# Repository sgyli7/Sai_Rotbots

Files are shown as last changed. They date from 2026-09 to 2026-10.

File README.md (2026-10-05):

# Sai_Rotbots

面向真实世界互动与任务的开源机器人工程。保留轮腿机器人 **Sai_Agent_001**、后备箱平整的 **Sai_Agent_002**，并开发 **Goose V0.1** 与大型双足双手机器人 **Gorilla V0.1**。仓库由 `Sai_Agent_001` 直接改名，提交历史和旧版本发布均保留。

| Robot | Cargo bay | Guide |
|---|---|---|
| Sai_Agent_001 | Original powered opposed pads and belt mechanism | [001](robots/Sai_Agent_001/README.md) |
| Sai_Agent_002 | Continuous flat floor, no moving clamp mechanism | [002](robots/Sai_Agent_002/README.md) |
| Goose_V0.1 | Long-neck biped with a gripping beak; initial training checkpoint | [Goose](robots/Goose_V0.1/README.md) |
| gorilla_v0_1 | AA3 appearance; C15 segmented-foot stage, physical gates open | [Gorilla](robots/gorilla_v0_1/README.md) |

## Gorilla V0.1：AA3 外形与复合脚阶段

Gorilla 以用户确认的 AA3 四视图为唯一外观基准，原图比例优先、高度暂取 2.65 m；目标是双足移动、双手操作与自主复杂任务。当前 [C15 阶段基底](robots/gorilla_v0_1/design/appearance_c15_stage.md)保存实际外壳、有限壁厚主框架和分段前掌/足弓/后跟；已提供同源可编辑模型、七机位实渲及有界几何检查。

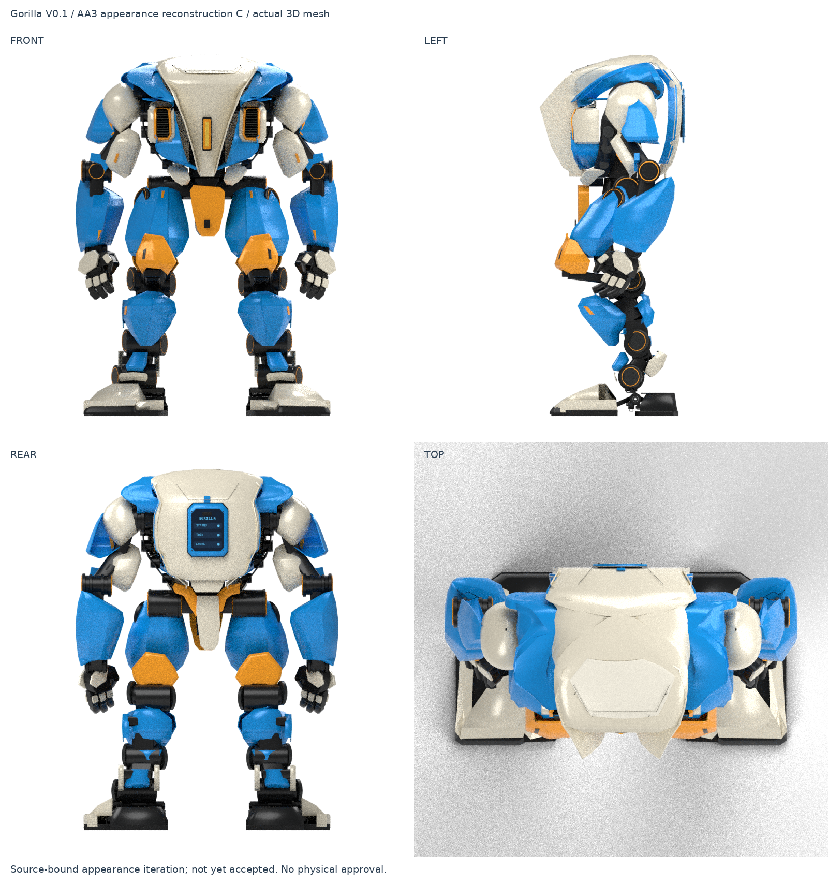
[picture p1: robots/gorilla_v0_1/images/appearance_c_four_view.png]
Gorilla C15 actual source geometry


这是一份可回退的探索候选，外观、完整内部装配、锁止承力和稳定物理合同仍未放行。历史 B 的运行模型与 C15 显示几何分别保留版本；Gorilla 不使用现有轮腿控制器或策略，Bevy 原生物理任务尚待后续验证。下一阶段先闭合真实内部模块的质量、空间、输出、供电与热预算，再细化壳体。

## Goose V0.1：一只幽默又实用的机器人鹅

Goose 的初衷来自 [Untitled Goose Game](https://goose.game/)：把鹅的好奇、探头、歪头、回望、动作停顿和叫声带进真实世界，也让它能帮人做小事。**叼起物品和拖拽物体同等重要**；目标包括指定轻量日用品、布边、空拖鞋、轻篮及小车，支持遥控和“叼过来／拖到指定位置／放下”的指定物自主任务。这些是设计目标，完整任务能力仍待验证。

我们将它视作 [MicroDuck](https://github.com/pollen-robotics/microduck) 的“Max Pro”方向：借鉴双足互动机器人的经验，增加头颈活动范围、真实嘴部夹持和腿脚机动。外观追求简约的鹅感，以可打印曲面、大眼、橙色嘴脚和两侧手动检修门表达角色；检修门不画写实羽毛。最终外观须与实际制造装配一一对应。

### 当前工程装配

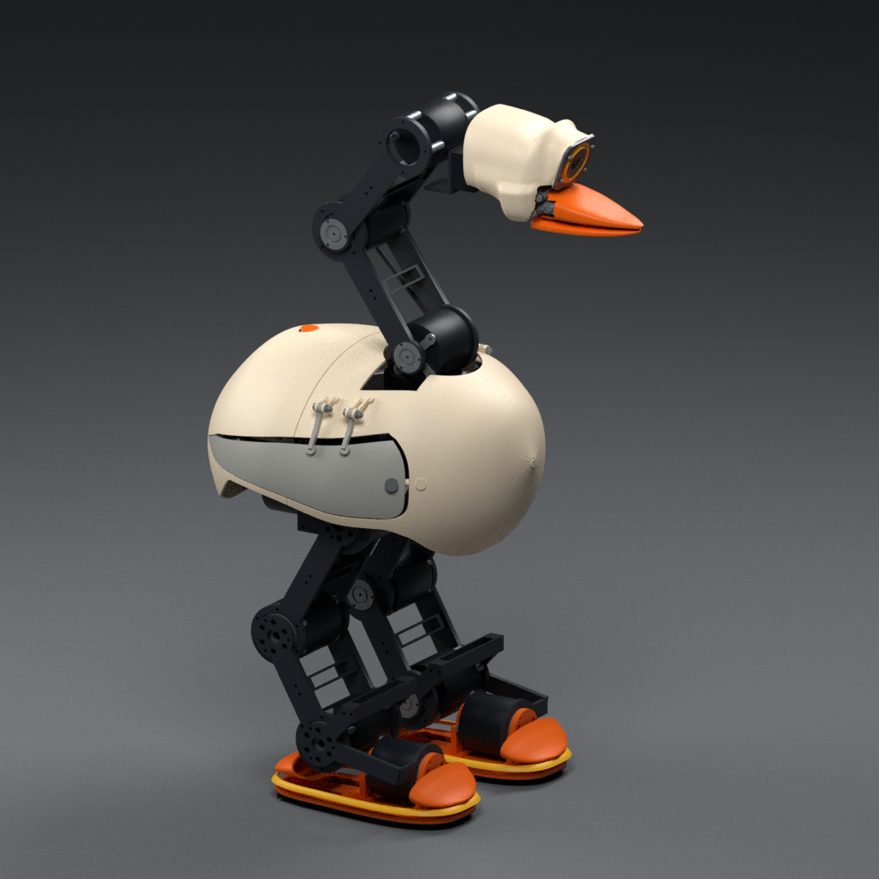
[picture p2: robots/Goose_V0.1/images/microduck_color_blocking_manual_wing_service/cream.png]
Goose V0.1 当前手动翼门候选实际装配渲染


上图直接来自当前 **478 件候选源装配**，不是实物照片或最终制造验收图。单件打印主头壳、相机面板、夹嘴和深色承力结构分别承担实际功能。当前候选有 **18 个主动轴、约 10.40 kg 条件质量**；闭合零位包围尺寸约 **43.4 × 26.7 × 64.2 cm**（长 × 宽 × 高），姿态变化会改变外部包围尺寸。质量含设计预留，尚非实物称重。两侧检修门已加入实际手动铰链和关闭保持；上沿接缝和外露支臂仍待最终审美与制造资格。

| Cream 奶油白 | Graphite 石墨灰 |
|---|---|
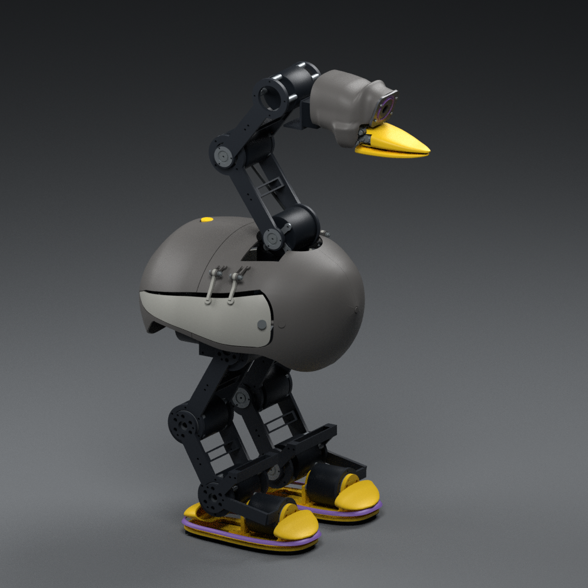
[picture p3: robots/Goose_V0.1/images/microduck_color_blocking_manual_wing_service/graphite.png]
Graphite
| Cream |  |
| Lavender 薰衣草紫 | Sky 天空蓝 |
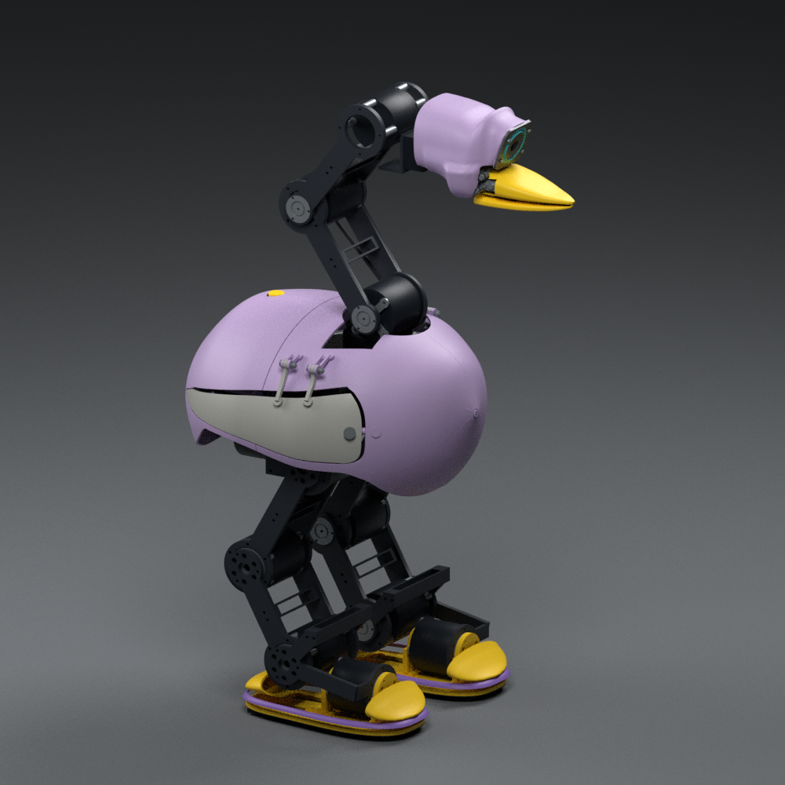
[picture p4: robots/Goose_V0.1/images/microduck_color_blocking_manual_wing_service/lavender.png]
Lavender
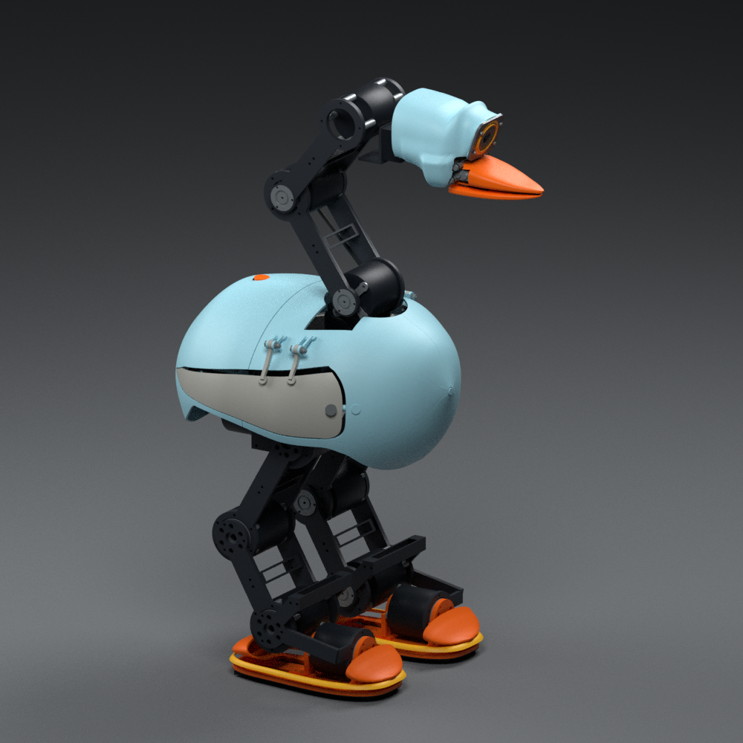
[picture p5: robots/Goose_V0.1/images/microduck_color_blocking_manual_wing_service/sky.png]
Sky
|  |  |

四款使用同版几何、同镜头与灯光，分别配置主壳、中性检修门／脸板、深色骨架、嘴脚及眼圈／鞋边辅色；见[配色与源身份记录](robots/Goose_V0.1/design/manual_wing_service_checkpoint.md)。

### 设计图与外观演进

| 早期 R2 尖嘴概念 | 已确认的阶段性外观基线 |
|---|---|
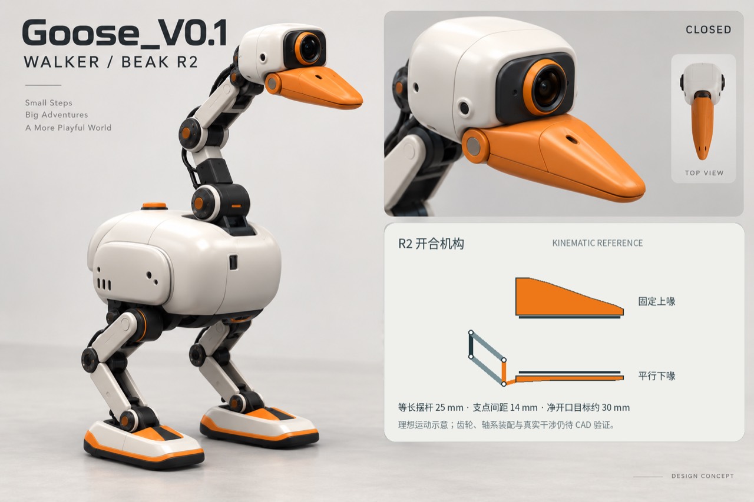
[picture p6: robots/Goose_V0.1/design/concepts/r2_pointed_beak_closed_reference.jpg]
R2 尖嘴概念图
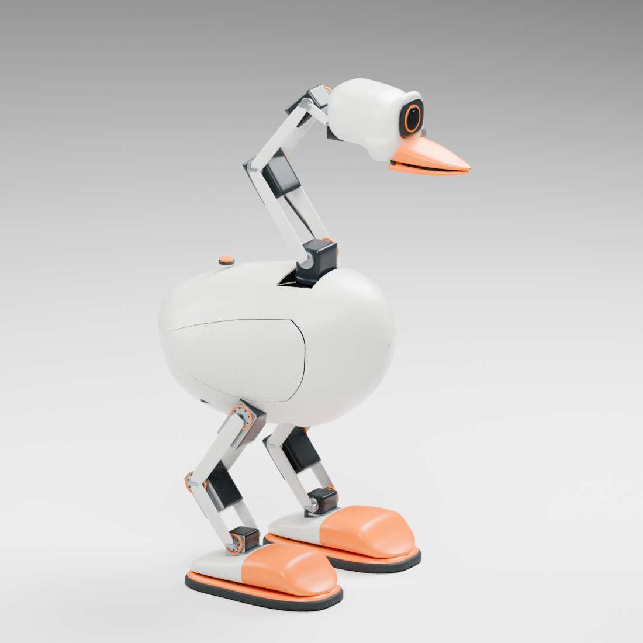
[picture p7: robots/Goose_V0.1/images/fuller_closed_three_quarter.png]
饱满机身、大眼与鹅掌外观基线
|  |  |

这些图保留设计意图和演进过程。右侧[外观基线](robots/Goose_V0.1/design/fuller_exterior_review.md)曾获阶段性确认；之后按真实器件、承力和装配需求继续调整。概念图上的旧尺寸与性能不作为当前工程参数，当前手动翼门候选仍需最终审美与制造验收。

### 当前交付与下一步

**直接查看：[优化后的11碰撞体示意图](robots/Goose_V0.1/images/task_proxy_11_v1_colliders.png) · [碰撞体文件目录](robots/Goose_V0.1/models/task_proxy_11_v1/)。**

当前 Sim2Sim 入口是[11 个碰撞体的任务代理](robots/Goose_V0.1/design/task_proxy_11_v1.md)，绑定[同版入口与契约](robots/Goose_V0.1/configs/task_proxy_11_v1_entry.json)。硬件 CAD、打印源、BOM、质量与完整惯量保持独立；MuJoCo 与原生 Rapier 各完成 2,500 次实际积分，通过冷启动、站立、有限关节动作、嘴部行程和负载／摩擦检查。18 项动作、65 项基础观测及 82 项指定物扩展可供 Sai_Lab 绑定新策略；这不代表已学会行走、转向、拾取／拖拽或适应复杂地面。Godot/Jolt、Unity 仍需各自验证。

当前[478件结构检查点](robots/Goose_V0.1/design/manual_wing_service_checkpoint.md)有独立CAD/SI与采购增量；003运行模型继续绑定原来的10.430690821kg参数，不混用新版硬件质量。[精确驱动资料及18轴端点](robots/Goose_V0.1/hardware/power_release_checkpoint.md)已补齐电压、插头及型号协议范围；新增[绝对阈值制动电路候选](robots/Goose_V0.1/hardware/absolute_brake_chopper_checkpoint.md)通过原生连通、条件角点和实际NGSPICE行为/故障对照，仍未取得PCB、热与完整安装资格。完整安装与线束、翼门连续开合和接缝、供电保护和独立急停、真实电机额定及热／载荷检查仍未闭合，**不能直接按候选 BOM 下单装机；第三、第四阶段和硬件冻结尚未完成**。原交接图片、文档、采购表以及成功／失败记录均保留，历史模型的结果不替代当前版本验证。

后续[制动安装比较](robots/Goose_V0.1/hardware/brake_packaging_checkpoint.md)补上48件独立CAD增量、525件装配源和10.486951740kg条件参数，并复查有限转向／低姿态与同版静力。它保留PCB、热／工具／线束和连续扫掠门槛；运行模型继续使用003的11个凸碰撞体。

从[Goose 资料入口](robots/Goose_V0.1/README.md)、[新版独立接收器与复测命令](integrations/bevy/goose_task_proxy/README.md)、[历史 460 件训练交接](robots/Goose_V0.1/design/training_checkpoint_handoff.md)、[单件头壳结构](robots/Goose_V0.1/design/one_piece_head_checkpoint.md)、[行为要求](robots/Goose_V0.1/design/behavior_requirements.md)继续；[原始资料图片库](robots/Goose_V0.1/design/concepts/index.html)与[导入记录](robots/Goose_V0.1/source/workspace_import.md)保留溯源。大型 Blender／OBJ 资产须按 [Git LFS 拉取说明](docs/guides/large_asset_checkout.md)获取完整内容。

## Project organization

Robot-specific design, models and evidence live under `robots/<robot_id>/`.
Shared policies and configurations live under `shared/`; common software lives
under `src/sai_agent/`, with categorized command entrypoints in `scripts/`.
Local generated runs belong in `artifacts/<robot_id>/<run_id>/` and are not committed.

Read the [engineering rules](sai_robots_engineering_rules.md) before adding or
moving files. The [migration record](docs/guides/directory_migration.md) maps old
paths to their new locations without rewriting historical experiment records.

Both variants retain the front SO101 arm, four wheel-legs, camera mounts and
rear touchscreen layout. Hardware has not been built or calibrated.

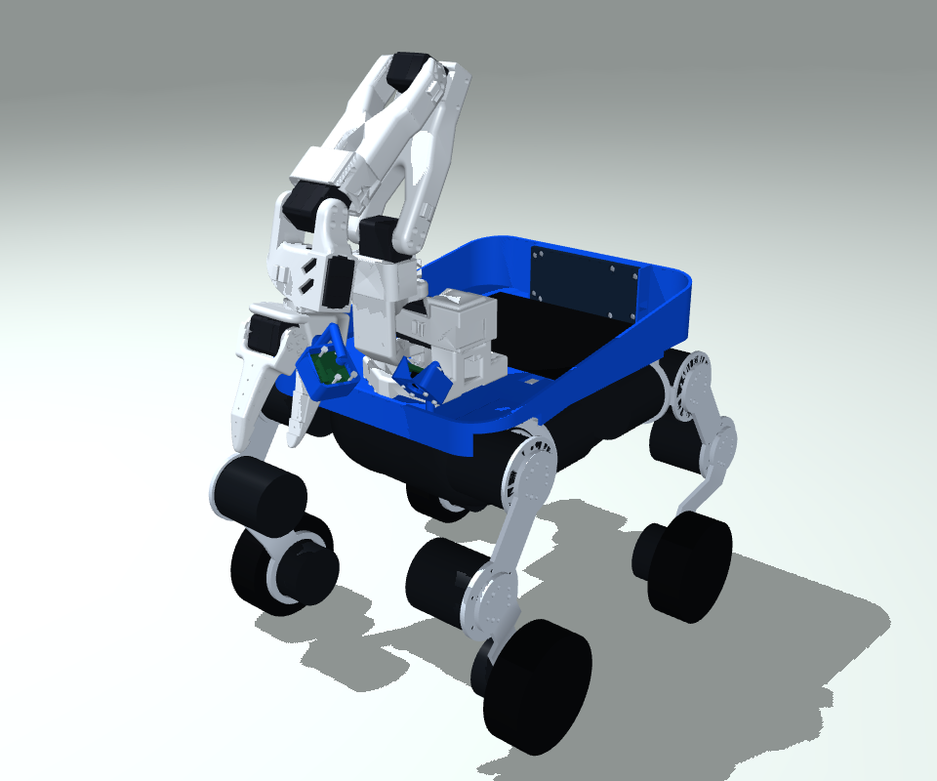
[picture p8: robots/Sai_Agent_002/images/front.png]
Sai_Agent_002 actual model

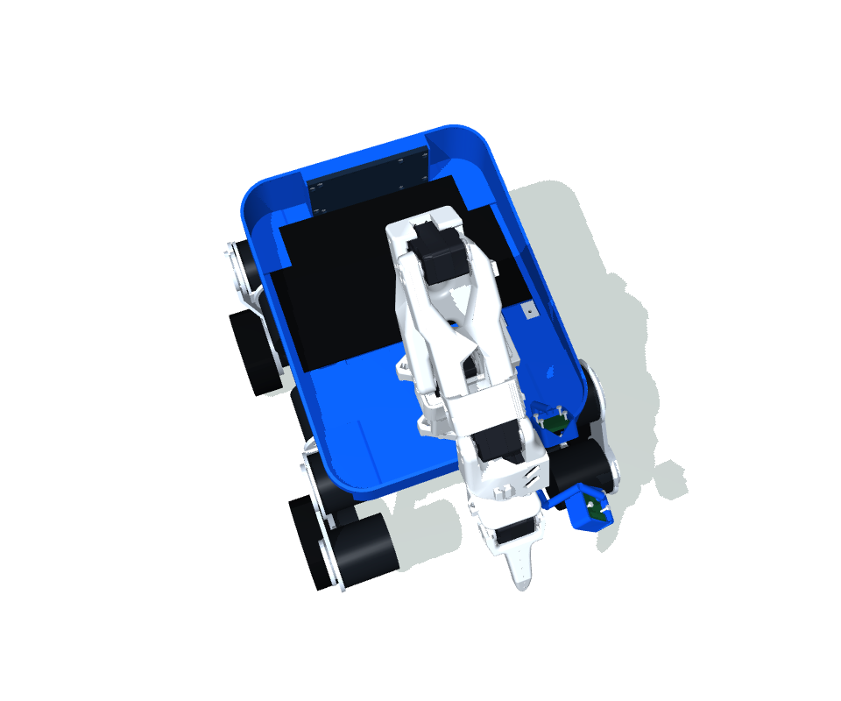
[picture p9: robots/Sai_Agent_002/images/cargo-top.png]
Sai_Agent_002 cargo surface


## Run in Godot

Python 3.12, Godot 4.7.2 and `uv`:

```sh
uv sync
uv run sai-agent godot --robot Sai_Agent_002
uv run sai-agent godot --robot Sai_Agent_001
```

W/S 前进后退，A/D 左右转向，按住 Shift 下蹲、松开恢复，R 重启。
Omitting `--robot` preserves the original 001 default.

```sh
uv run sai-agent godot --robot Sai_Agent_002 --task cargo
uv run sai-agent godot --robot Sai_Agent_002 --stairs .04
```

002 uses contact-only pickup → placement → passive transport. It has no
clamping stage or cargo attachment constraint. Objects can slide or fall;
this variant does not promise automatic load restraint. Camera images are
available but the current tasks use model-state IK and terrain raycasts,
not VLA. The touchscreen remains a hardware layout, not implemented firmware.

## Models, training and integrations

[`robots/catalog.json`](robots/catalog.json) maps stable robot IDs to separate
model directories. Shared controllers/policies are retained; new robots can add
catalog entries and their own model directory. The `sai-agent-001` Python
package name and `sai_agent` import remain for existing integration compatibility.
The repository name is `Sai_Rotbots` as requested, including that spelling.

```sh
uv sync --extra test --extra cad --extra assets --extra hardware
uv run pytest -q
uv run python scripts/evaluation/evaluate_flat.py --robot Sai_Agent_002 --policy shared/policies/flat-v1.onnx --full-robot --out artifacts/002-flat --require-pass
uv run --extra train python scripts/training/train.py --robot Sai_Agent_002 --worlds 256 --seconds 300 --name my-002-trial
```

The variant reuses existing trained actors and is checked on its changed
mass/contact model. It is not presented as a newly trained policy. GPU training
accepts `--robot`; each run records the selected model hash and robot ID.

See [002 scope and evidence](robots/Sai_Agent_002/README.md),
[game integration notes](docs/guides/integrations.md),
[001 historical acceptance](robots/Sai_Agent_001/design/simulation_guide.md),
[variant plan](robots/Sai_Agent_002/design/agent_002_plan.md), and [third-party notices](THIRD_PARTY_NOTICES.md).
Old alpha.3 results describe 001, not 002. Unity editor validation remains pending.

SO101 and Raspberry Pi derivatives retain their upstream licenses. Supplier
CAD with unconfirmed redistribution rights is represented by independent
nominal display envelopes. Physics parameters are documented estimates, not
measured hardware values. Inspired by [MicroDuck](https://github.com/pollen-robotics/microduck)'s
functional design philosophy; the wheel-leg cargo chassis is an independent design.

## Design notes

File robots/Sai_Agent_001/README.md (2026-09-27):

# Sai_Agent_001

Preserved powered-clamp variant. It remains the default robot.
Its model data is unchanged by the directory migration; no 002 geometry is
substituted into 001. The catalog maps its stable ID to [`models/`](models).

| Material | Entry |
|---|---|
| Simulation and historical acceptance | [Simulation guide](design/simulation_guide.md) |
| Design and implementation record | [Implementation plan](design/implementation_plan.md) |
| Physical cargo task | [Cargo task](design/cargo_task.md) |
| Geometry and appearance concepts | [Concept study](design/concepts/design_presentation.md) |
| Open-source scope and missing hardware/CAD | [Scope and limitations](design/open_source_status.md) |
| Actual model and simulation images | [Images](images) |
| Frozen models and asset provenance | [Models](models) |
| Robot-specific verification | [Evidence](evidence) |
| Shared deployed policies | [Shared policies](../../shared/policies) |
| Historical experimental profiles | [Stair experiments](../../experiments/Sai_Agent_001/stair_profiles) |

Hardware has not been built or calibrated. The public clone contains audited
simulation assets, not the complete editable manufacturing CAD used historically.
Missing original design inputs remain documented rather than reconstructed
from presentation images.

From the repository root: `uv run sai-agent godot --robot Sai_Agent_001`.

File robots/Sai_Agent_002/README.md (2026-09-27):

# Sai_Agent_002

The simple open-bay variant: same SO101, four wheel-legs, outer blue shell,
camera placements and rear touchscreen as 001; no powered cargo clamp.

| Material | Entry |
|---|---|
| Design plan and changes | [Plan](design/agent_002_plan.md), [change record](design/changes.json) |
| CAD input and exports | [Source](cad/source), [exports](cad/exports) |
| Model generation inputs | [Source assets](source) |
| Simulation models and provenance | [Models](models) |
| Actual model and simulation views | [Images](images) |
| Robot-specific validation | [Evidence](evidence/validation.json) |
| Shared deployed policies | [Shared policies](../../shared/policies) |

Actual model, front
Actual model, cargo bay
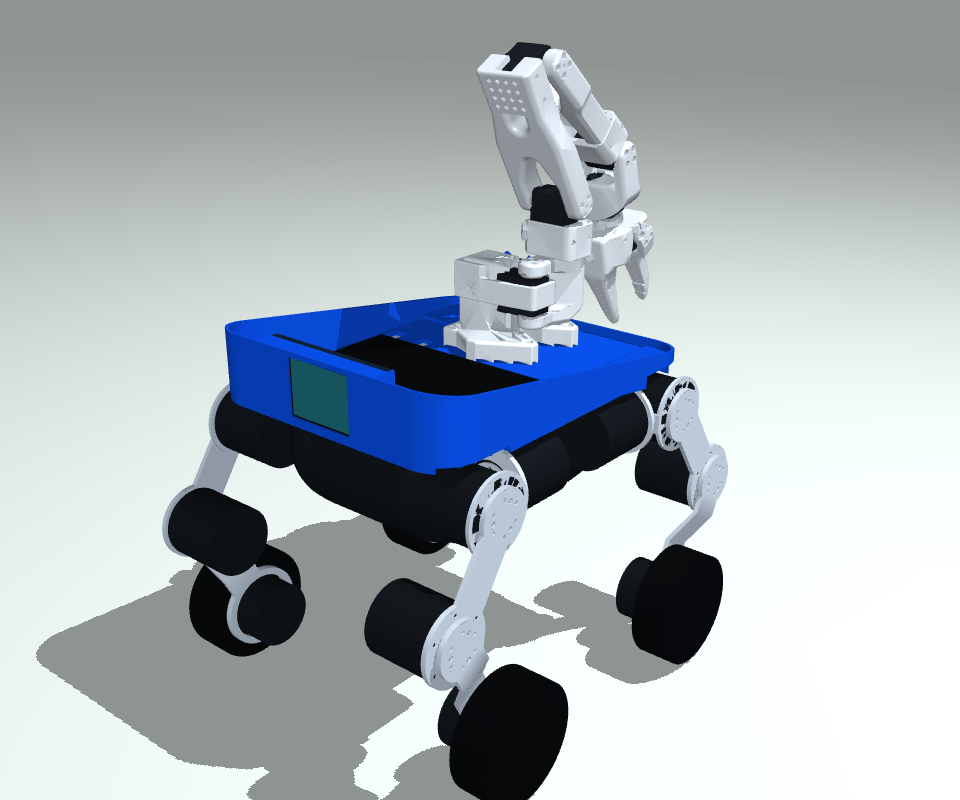
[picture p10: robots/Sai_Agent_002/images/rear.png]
Actual model, rear touchscreen


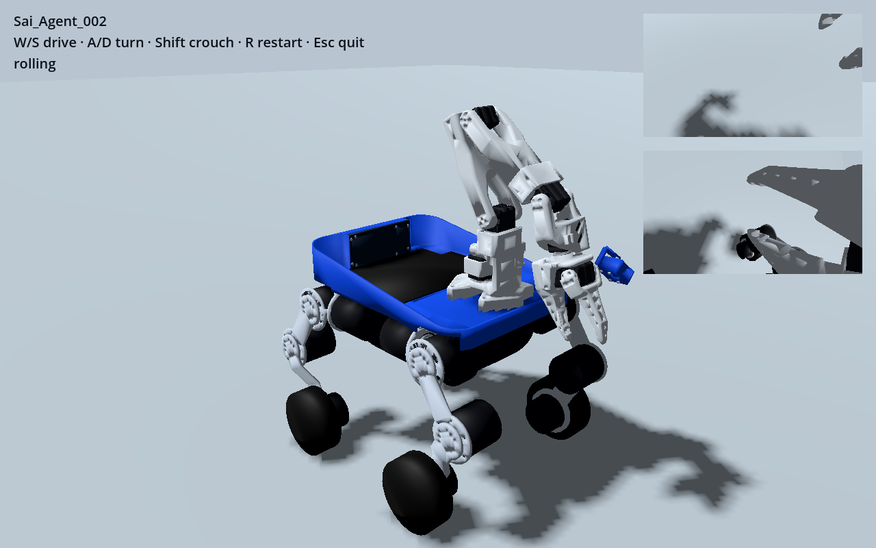
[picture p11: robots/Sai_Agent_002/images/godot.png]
Actual Godot run


These are rendered directly from the distributed geometry, not generated
concept images. The original arm pose is retained. A small rear screen service
cover and existing rim/hip structures remain at the edges; no cross-bay drive
cover, rail, moving pads or separate inner storage box remains.

## Changes

- Remove the opposed pad sliders, belt rotor, bearings, rail, servo and guard.
- Remove their force-board/load-cell system, dedicated cargo 6 V branch and
  cargo-only Maestro PWM board/mounts. Shared arm, leg, camera and display
  electronics are retained.
- Restore holes/slots in the original 4 mm cargo floor by a CAD boolean union.
  The continuous 2 mm non-slip mat is nominally 152 × 220 mm; its top stays at
  the original Z=259 mm in the design frame. This is an insert dimension, not a
  guaranteed usable-box envelope through the curved walls.
- The full model now has 22 actuators: 16 wheel-leg and 6 SO101 axes. There are
  no cargo joints and no belt/object constraints. The reduced training model
  retains all mass but fixes the arm at home, as in 001.
- Nominal estimated robot mass changes from 9.276 kg to 8.956 kg. Component
  mass, COM and inertia changes are propagated to both MJCF and Godot JSON.
  Unassigned hardware remains covered by the original 600 g allowance; the
  removed unassigned electronics are not given fabricated precise masses.

Detailed [removed-parts/change record](design/changes.json),
[physical manifest](models/robot_manifest.json) and
[part-level provenance](models/asset_provenance.json).

## Run and inspect

From the repository root:

```sh
uv sync
uv run sai-agent godot --robot Sai_Agent_002
uv run sai-agent godot --robot Sai_Agent_002 --task cargo
uv run sai-agent godot --robot Sai_Agent_002 --stairs .04
uv run sai-agent godot --robot Sai_Agent_002 --stairs .04 --descending
```

W/S forward/reverse, A/D yaw, held Shift crouch, R reset. Cargo uses the same
contact-only SO101 pickup and trained crawl policy, with a short settling phase
in place of active clamping. It has no artificial cargo attachment. Validation
records are collected under [evidence](evidence).

| Check on the actual 002 model | MuJoCo | Godot/Jolt |
|---|---|---|
| Eight movement/crouch commands | 8/8 | 8/8 |
| Four-riser 20/40 mm ascent/descent | 4/4 | 4/4 |
| Opt-in nominal 60 mm ascent/descent, 45 s budget | 2/2 | 2/2 |
| 100 g pickup and transport over 18/25 mm obstacles | 2/2 | 2/2 |

The inherited 60 mm profiles remain opt-in experiments:

```sh
uv run sai-agent godot --robot Sai_Agent_002 --stairs .06 --stair-skill ascent60
uv run sai-agent godot --robot Sai_Agent_002 --stairs .06 --descending --stair-skill descent60
```

See the variant's [validation record](evidence/validation.json). No inherited 001 result is relabelled as
a 002 result. Hardware/VLA/touch firmware and Unity editor validation remain
outside this simulation variant's verified scope.

GPU training also completed a 32-world, two-update (2,048-step) smoke run on
NVIDIA GB10 with the actual 002 reduced model. This verifies training execution,
not the quality of a new policy; deployment still uses the tested shared actors.

## Reproduce geometry

```sh
uv run --extra assets python scripts/models/build_agent002.py
uv run --extra assets python scripts/models/render_model.py --robot Sai_Agent_002 --out artifacts/002-review
```

The builder uses the preserved 001 model and checked-in, licensed per-part
chassis meshes. It removes mechanisms from the geometry **and** physical model,
recalculates chassis inertia and regenerates the training model and game GLB.
All non-chassis retained bodies are required to match 001 exactly.

The changed shell and mat have actual STEP geometry in [`cad/exports/`](cad/exports).
With build123d 0.11.1 and trimesh installed, the nominal floor edit is reproduced by:

```sh
python scripts/cad/restore_floor.py robots/Sai_Agent_002/cad/source/source_001_shell.brep robots/Sai_Agent_002/cad/exports
```

Those STEP files cover the changed project shell/mat, not a falsely certified
complete manufacturing assembly. The source BREP is project-owned. Existing
supplier hardware keeps the same 001 definitions and provenance. The shell
remains one valid solid; no motor, arm link or screen is rescaled to fit.

## Physical limits

Cargo retention is passive. The original walls and non-slip floor can retain
the tested small item, but loads may slide, bounce or fall on other terrain.
This is the deliberate functional difference from 001. No active restraint or
force sensing is claimed. Mass, friction, motor response and the filled
shell's COM/inertia remain estimates requiring hardware measurement.

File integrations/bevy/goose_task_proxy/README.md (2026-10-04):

# Goose task proxy receiver

Standalone native receiver for `goose_task_proxy_11_v1`. It constructs the real
Rapier multibody, all 11 exterior collision leaves, full SI inertias and actual
jaw loop. It does not modify Sai_Lab's existing production receiver or install a
policy. Python and Rust keep one 20 ms controller update and one integration.

From the repository or extracted handoff root:

```bash
python -m pip install -r integrations/bevy/goose_task_proxy/requirements.txt
cargo test --manifest-path integrations/bevy/goose_task_proxy/Cargo.toml --release --locked
cargo build --manifest-path integrations/bevy/goose_task_proxy/Cargo.toml --release --locked
PYTHONPATH=src python -m pytest tests/test_goose_task_proxy.py -q
PYTHONPATH=src python -m pytest tests/test_goose_collision_filters.py -q
PYTHONPATH=src python scripts/evaluation/check_goose_collision_filters.py \
  --native-probe integrations/bevy/goose_task_proxy/target/release/goose_task_proxy_native_probe
PYTHONPATH=src python scripts/evaluation/check_goose_task_proxy.py \
  --native-probe integrations/bevy/goose_task_proxy/target/release/goose_task_proxy_native_probe
PYTHONPATH=src python scripts/models/build_goose_task_proxy.py --out artifacts/goose_proxy_reproduced
python scripts/models/package_goose_task_proxy.py --out artifacts/Goose_V0.1/goose_task_proxy_11_v1.zip
```

After extracting the ZIP into a fresh directory, run
`python scripts/models/package_goose_task_proxy.py --verify .` there, then repeat
the build, tests and evaluation above. The manifest hashes each package input;
the ZIP/extraction test report is outside the archive to avoid a hash cycle.

On Windows, append `.exe` and set `PYTHONPATH` with the shell's environment syntax.
The Python runtime is `sai_agent.goose.task_proxy_runtime.TaskProxyRuntime`, loaded
with the model and contract paths from the unique entry JSON. Locomotion/recovery
use 65 observations; pickup uses the typed `TaskGoal` extension to 82. The motor
input rotor is driven; jaw output feedback remains the sixth policy axis.

This entry passes bounded M0 engineering checks. It does not certify learned
walking, recovery, pickup/dragging, terrain, hardware or other engines. The custom
contact branch is explicit and pinned. The four flat-floor sole integration
points per foot are material samples, not additional collision shapes. Source
contact quadrature assumes a horizontal plane and an upright sole; other poses
must be independently validated before task acceptance.

The new receiver checks the exact plant/control binding and candidate revision.
It also rejects an exclusion list that differs from the source contract. The
companion collision policy lists all 55 role pairs, including implicit direct
parent filtering: nine connected pairs ignored, 46 retained. Each backend's
97 deliberate-overlap fixtures verify internal, ground, object and cross-robot
filtering. These fixtures are diagnostic placements, not physical pose tests.
The fork's opt-in frictional spring path retains the native Coulomb solver, with
load/slip regression fixtures. PGS passes converge one integration, without
subdividing physical time. See the contact fork's `GOOSE_CONTACT_CHANGES.md` and
Goose's task-proxy design note for provenance and approximations.

The additional Godot/Jolt filter-only diagnostic uses the same 11 hulls and
effective 55-pair policy. It passes 97 policy/environment/instance fixtures,
55 unfiltered controls and seven rejection/lifecycle checks in Godot 4.7.2:

```bash
PYTHONPATH=src:. python scripts/evaluation/check_goose_godot_collision_filters.py
PYTHONPATH=src:. python -m pytest tests/test_goose_godot_collision_filters.py -q
```

`integrations/godot/goose_collision_filters/collision_policy.gd` is a reusable
instance-scoped helper. Create joints, call `configure_joint` to clear their
default collision exclusions, then apply and read back the complete policy.
These artificial 1 kg fixtures are separate from whole-robot Jolt dynamics;
the old Godot adapter is not promoted. `--engine GodotPhysics3D` is an optional
rejection diagnostic: its deep-overlap queries/contacts currently fail and
cannot inherit the Jolt result. The new ZIP retains that failure record.

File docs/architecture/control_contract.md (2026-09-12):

# Control contract (development v1)

The robot has sixteen locomotion actuators: FL, FR, RL, RR, each ordered HAA,
hip, knee, wheel. The articulated model additionally retains five SO101 arm
axes, its gripper and the cargo belt drive. Two cargo pads are passive slide
joints coupled to that drive. The object remains free during manipulation.

W/S requests signed body-forward velocity; A/D requests yaw rate. Shift sets a
35 mm lower nominal chassis-height reference, slewed over half a second. Releasing
Shift returns to normal. Zero movement input explicitly commands wheel braking
and analytical standing/crouch IK, rather than allowing a residual-policy bias to
move the vehicle. This uses bounded motor torque; it does not fix the base pose.

All shared state is SI, right-handed X-forward/Y-left/Z-up. Quaternions are wxyz.
The policy runs at 50 Hz. Wheels use velocity feedback with gain 0.4 and a 1.3 Nm
cap; leg position feedback is 80/2 with an 8 Nm cap. These are simulation settings,
not measured continuous hardware ratings. Full-model arm holding uses the existing
998.22/2.731 settings, gravity feedforward and 2.94 Nm (1.4 Nm gripper) caps.

The ONNX actor takes one float32 `obs` tensor, shape [batch,82], and returns one
`actions` tensor, shape [batch,16]. Observation normalization is inside the model.
Never normalize it a second time. The deterministic actor outputs are clipped to
[-1,1] before reference construction and filtered to zero on a stop command.

| Slice | Meaning |
|---|---|
| 0:3 | World up expressed in body coordinates |
| 3:6 | Body linear velocity |
| 6:9 | Body angular velocity |
| 9:12 | Forward command, yaw command, current slewed crouch fraction |
| 12:24 | Twelve leg joint positions in manifest order, excluding wheels |
| 24:36 | Twelve leg velocities × 0.1 |
| 36:40 | Four wheel velocities × side sign × 0.1 |
| 40:56 | Previous applied/filtered action |
| 56:58 | sin/cos reference phase; flat 2.4 s, stair reference 3.2 s |
| 58:82 | 24 local height samples, transformed by the rule below |

The sampling grid has x = [-0.36,-0.18,0,0.18,0.36,0.54,0.72,0.90] and
y = [-0.24,0,0.24] metres, x-major order, aligned to body yaw. Each sample is
`clip(5*(ground_height - (base_z - 0.2192)), -2, 2)`.
The simulation height field is an explicit privileged terrain sensor. A camera
depth/height reconstruction backend has not been implemented or validated;
the package does not claim RGB-only/VLA stair navigation or real-hardware transfer.

Flat reference and the experimental stair gait are in `src/sai_agent/control.py`.
They have different phase/reference semantics even though their tensor sizes match;
a stair actor must not be loaded into a flat controller solely because the shapes fit.
The policy must be selected by its contract identifier and hash.

## Godot steering feedback

The flat ONNX and its 82D observation remain unchanged. Deployment additionally
integrates the requested yaw rate and uses actual body yaw/gyro to correct wheel
speed: `clip(1.5 * wrapped_heading_error - .25 * yaw_rate_error, -.4, .4)` rad/s.
The differential-wheel conversion is the same `.146/.048` geometry as the
reference. It resets its heading reference while parked; no body pose is forced.
Godot flat acceptance includes this `heading-v1` layer, not the raw actor alone.

Stair policy `stairs-dev40` uses a 3.2 s phase and the bounded lift/stride reference
in `targets_stairs_numpy`. Its development evidence is reduced-model CPU MuJoCo
20/40 mm ascent/descent. The automatic game selector also passes the four 20/40 mm Godot cases;
untested terrain remains experimental. Ground rays are privileged simulator sensing, not RGB/VLA output.

## Numerical GPU regression

A finite stair state with a previous solver acceleration guess reproduced
non-finite Warp states in 307/320 worlds. Zeroing that guess before each 50 Hz
control interval removed the captured failure; states, forces, contact geometry
and model parameters are unchanged. The diagnostic fixture and script retain
both failure and corrected modes. This does not assert every numerical failure
has been eliminated.

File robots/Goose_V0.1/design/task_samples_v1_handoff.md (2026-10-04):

# 指定物虚拟输入 v1｜004 冻结机器人

2026-10-04。本批补齐 Lab 已冻结的 **100／200／300g、圆柱抓杆与把手样件**，供指定物训练接收。站立、移动及恢复训练继续使用原 004；PCB、采购与制造不作为等待条件。本批没有改变机器人 CAD、SI、18轴、11凸叶、过滤或65／82维观测。

入口：[物品目录及全部SI](../models/task_samples_v1/object_catalog.json)、[同源精选证据](../evidence/task_samples_v1_handoff.json)。6个正式模型另有2个50g开发模型，50g不替代Lab的三档正式载荷。完整拾取、接触质量、GPU及实物资格均未通过本批检查授予。

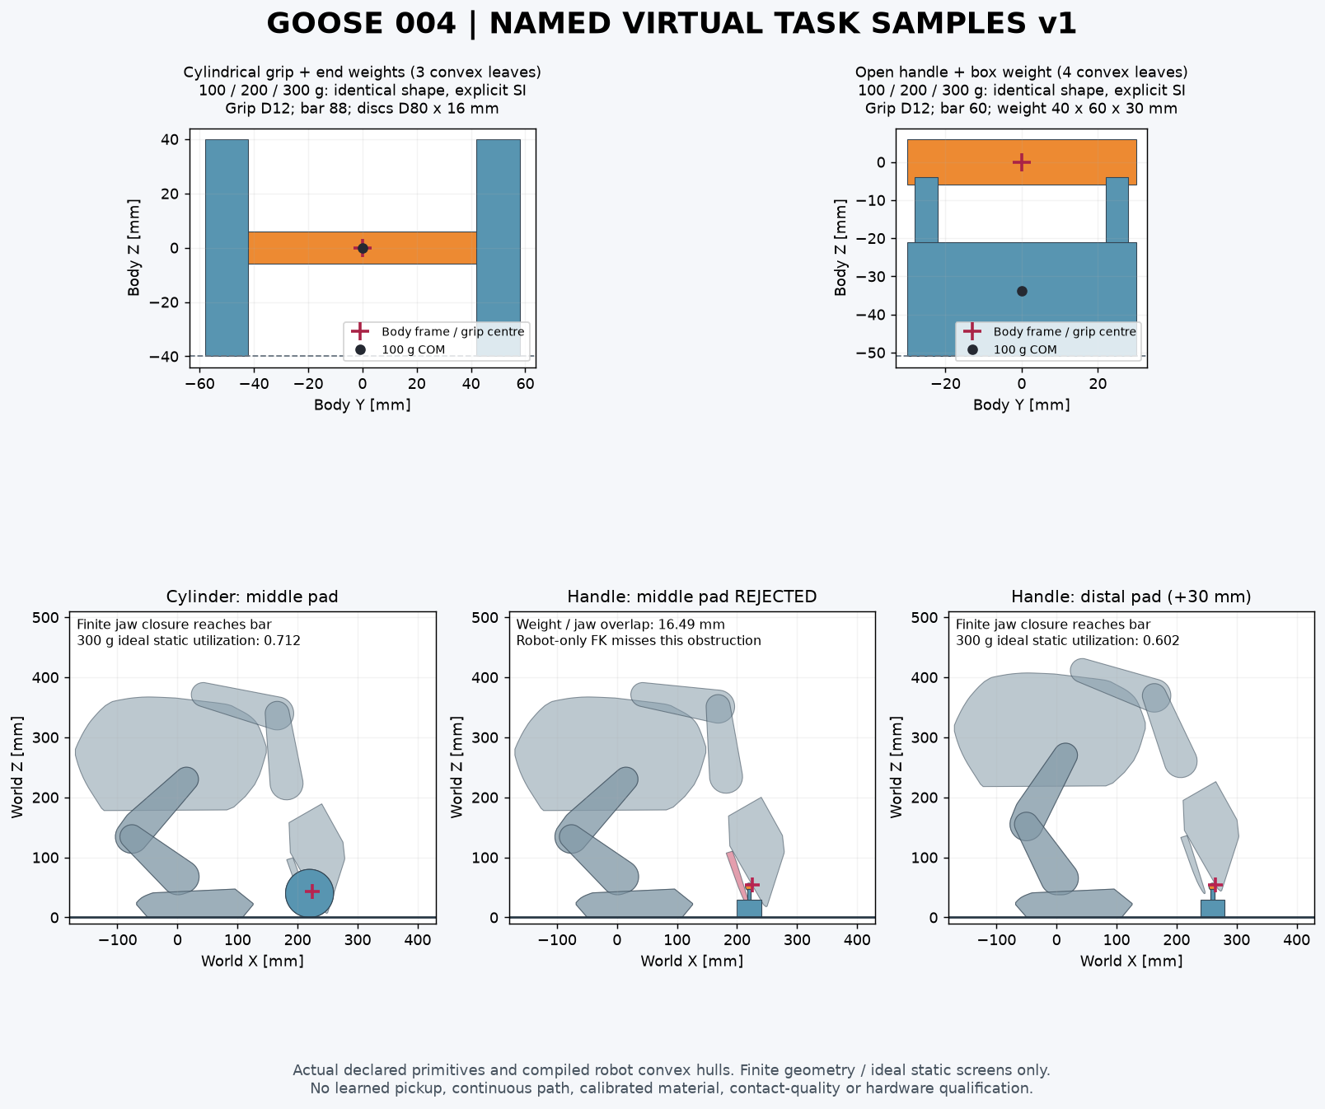
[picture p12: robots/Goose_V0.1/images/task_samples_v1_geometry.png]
实际样件与有限地面姿态


## 样件与坐标

| 家族 | 明确几何 | 动态体／凸叶 | 地面抓杆中心高度 |
|---|---|---:|---:|
| `cylinder_weight` | 横向圆柱抓杆直径12、长88mm；两端配重盘直径80、厚16mm，中心Y=±50mm | 1／3 | 40mm |
| `handle_weight` | 横向抓杆直径12、长60mm；两根直径6、长24mm竖杆；40×60×30mm配重箱，中心Z=−36mm | 1／4 | 51mm |

模型命名为 `<family>_<100/200/300>g_v1.xml`，三档使用相同几何，分别序列化完整质量、COM及COM处惯量张量。杆／盘／箱在同一刚体内可交错；惯量来自显式声明的分件质量和并轴合成，碰撞几何密度置零，不能让接收器按外包络重新估算质量。这是虚拟样件定义，尚无真实购买或打印材料标定。

物体body原点是**抓杆中心**，不是COM。沿用既有TaskGoal的物体body `xpos/xquat`；惯量与COM独立读取。箱式样件COM在原点下方约34～35mm。落地出生及目标放置高度须计入目录的原点到最低面距离，不把body原点放在Z=0。任意旋转下的最低点须重新计算。

摩擦μ=0.65是声明的虚拟假设。物品`priority=2`使它的μ控制物品／机器人及物品／地面的原生接触；`condim=3`、`margin=0`、`solref=.005 1`、`solimp=.95 .99 .001`。contype=1／conaffinity=3保留外部接触。没有物品焊接、吸附或额外抓持约束。样件的3／4叶另计入场景，不改变机器人11叶预算。

可在MJCF根下分别include既有robot.xml及一个样件XML。对6个正式样件逐一原生编译，核对新增1个自由体／7个qpos及源机器人逐体质量、COM、完整惯量不变。不要把本批物品覆盖成新的机器人入口，也不要继承物品材质或任务资格。

## 真实嘴部与地面边界

原生烹制后的凸包，在零位世界X=220mm、Y=0截面：jaw=0.1／0.2／0.3／0.4／0.55rad对应垂直开口约6.136／12.630／19.635／27.339／40.765mm。开口不是恒定的“平行30mm”；转到嘴尖附近时，下喙截面可能已离开该X位置，须查实际最近距离。完整截面区间在证据内。

有限搜索固定双脚平地，躯干下沉0／40／70／90mm，物体抓点X=220／260／300／340mm，头俯仰0／0.35／0.7／1.05／1.4rad；比较原`grip`及其head局部X向+30mm的实际嘴垫位置。后者仍在源夹面轮廓内，**没有新增site或改观测合同**。

共320个组合，50个机器人自身／地面几何可行；再查询每一物品叶与全部11个机器人凸包，只有35个实际样件端点可行：圆柱22、把手13。把手在原`grip`的15个机器人可行姿态全部失败，下喙碰配重箱13.85～16.49mm；只看抓杆可达会漏掉此问题。把手的13个可行端点均使用+30mm嘴垫位置。

对35个端点逐个采样闭嘴，按真实四杆关系更新主动／被动坐标，首次下喙接触抓杆前未发现其他超过0.2mm的物品、自身或地面穿透。0.02rad采样会越过首次接触约毫米级，遇接触即停止；它不能证明连续进场、带载闭合或防滑。

| 参考端点 | 躯干下沉 | 物体抓杆世界坐标m | 头俯仰 | 300g理想连续力矩利用率 |
|---|---:|---|---:|---:|
| 圆柱、原嘴垫 | 40mm | (0.22,0,0.04) | 1.05rad | 0.712 |
| 把手、嘴垫+30mm | 0mm | (0.26,0,0.051) | 1.05rad | 0.602 |

35个端点×3档质量均通过理想静力必要条件，最高利用率0.915。使用完整源质量、实际Jacobian、自由基座六维力／矩平衡、8个足底支持点和μ=0.65摩擦菱形；负载按名义COM重力传到头部。所有18轴力矩、支持力和qpos均保留，广义重力另外用独立势能有限差分核对。这不含夹紧内力、防滑压力、软垫相容性或PD保持，不能称完整载物平衡通过。

## 接触台架与拒绝边界

另用原样两片嘴凸包及四杆，把头固定、样件自由，预置在嘴口，执行有界局部jaw PD。每个正式样件375次实际20ms积分；后250步=5s双嘴均有正法向力，6个样件全部达到这一局部指标。两家族100g的零摩擦／零驱动力4个反例均无法达到双面保持。

但正式样件仍有最大 **3.47～6.82mm接触穿透**、jaw最大 **1.247～1.552rad/s**（超过1rad/s设计值）、闭环坐标残差最大约0.83mm及持物漂移。目标速率限制／速度转矩降额不等于实际速度硬限。故接触质量和完整拾取均为false；不得把这6个台架结果当成GPU、18轴运行控制或学会拾物。中部台架也未验证前端嘴垫的动态抓握。

Lab接收本批几何／SI／端点与反例，负责源端接触准入、出生及完整任务。站立／移动PPO继续；拾取的接触质量和完整抬起、保持、移动、转向、放置按Lab计划独立验收。材料、真实样件及制造随后单独标定。

## 复现

从仓库根运行，使用Python3.12、MuJoCo3.10、NumPy、SciPy；制图另外需要Matplotlib。原始场景与轨迹落在被忽略的artifacts目录，精选结果和输入哈希入库。

```bash
PYTHONPATH=src python scripts/models/build_goose_task_samples.py
PYTHONPATH=src python scripts/evaluation/check_goose_sample_contact.py --out artifacts/Goose_V0.1/task_samples_v1_domain/contact_closed_envelope
PYTHONPATH=src python scripts/evaluation/check_goose_sample_ground_static.py
PYTHONPATH=src python scripts/evaluation/check_goose_sample_pose_contacts.py --poses artifacts/Goose_V0.1/task_samples_v1_domain/ground_static.json --out artifacts/Goose_V0.1/task_samples_v1_domain/native_contacts
PYTHONPATH=src python scripts/evaluation/package_goose_task_samples_handoff.py --run artifacts/Goose_V0.1/task_samples_v1_domain
PYTHONPATH=src python -m pytest tests/test_goose_task_samples.py tests/test_goose_task_proxy.py tests/test_goose_collision_filters.py tests/test_goose_contact_domain_diagnostic.py -q
```

本批29项针对性测试通过，覆盖独立SI编译、6个原生组合include、物体坐标合同、摩擦负对照、势能重力核对、真实配重箱碰撞反例及已有代理／过滤／倒地诊断回归。

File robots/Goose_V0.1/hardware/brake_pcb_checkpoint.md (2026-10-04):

# 制动板：原生 ECAD 与安装包络检查点

2026-10-04。[独立配置](../configs/brake_pcb_candidate.json)把上一轮制动电路推进为可编辑的 [KiCad 原理图](brake_pcb_candidate/brake_pcb_candidate.kicad_sch)、[PCB](brake_pcb_candidate/brake_pcb_candidate.kicad_pcb)及随项目保存的自定义焊盘库。**连通和几何 DRC 已通过；整机供电、制造及采购仍未放行。** 本版没有替换478件硬件基线、525件制动安装候选或11凸体运行包，也没有继续PPO。

| 实有交付 | 验证范围 |
|---|---|
| 80×50×1.6mm 双层板，44个板上元件、8个外置电阻 | 15个电气网络、141个原生原理图连通针脚，44个PCB与原理图实例关联 |
| 35条信号连接及BUS／制动回路／地铜区 | 原生KiCad7.0.11 DRC为0违规、0未连接、0封装错误；独立复制项目后重复通过 |
| 45件包络BREP、闭合quad采样及STEP | 全部位于前轮PCB预留内，STEP回读保留45个实体；不是原厂精细器件CAD |
| [候选清单](brake_pcb_candidate/candidate_bom.csv) | 精确器件、目录订货码候选和未定无源件分别注明；不能直接作为采购放行单 |

[构建记录](../evidence/brake_pcb_native_check.json)、[原生DRC](../evidence/brake_pcb_native_drc.txt)、[复制及反向检查](../evidence/brake_pcb_native_reload.json)与[原生几何记录](../evidence/brake_pcb_envelope_check.json)绑定本版源哈希。故意把U1焊盘叠到同一点，检测到93项违规和4个未连接；移除反馈中点走线，检测到1个未连接。反例使用同一封装库，另行核实改动实际序列化，避免用缺库警告冒充发现电气故障。电路、封装／报告拒绝及原有制动安装的42项测试通过；这些不是整机全部测试。

## 电路与封装依据

固定输出LDO采用DGN8图纸，不误用DRB；比较器采用DBV5，不误用DCK。SVPF电容检查安装底座宽度与最大高度，使用10.5mm底座包络、12.7mm高度，不能只看标称10mm罐体直径。MOSFET大漏极焊盘依据原厂图纸重建，独立复核仍待完成。

按[Yageo RT目录](https://yageogroup.com/content/datasheet/asset/file/PYU-RT_1-TO-0-01_ROHS_L)的25ppm/°C、0.1%范围，0603反馈改为两只825kΩ串联，保持总值1.65MΩ；中点仅连接两只电阻，未改变比较器反馈的理想阈值。订货码是目录候选，库存未核实。补入基准输入及驱动输入的局部电容、比较器旁路和LDO PG延迟电容。PG目前仅引到监测端，尚未形成独立硬件使能链。

提出的叠层为两面70µm铜、1.44mm芯板及两面10µm阻焊；原生PCB文件保存此叠层，板厂能力尚未确认。焊盘内接地过孔需要填孔／盖铜工艺；不能把普通开孔过孔当作等价已合格焊接方案。DRC检查铜间距和连通，不计算载流、铜温、寄生电感、均流或响应上界。原理图符号的引脚均为被动类型，原生网表正确**不等于ERC资格**。

## 合回整体的边界

板背面原点为原生机器人毫米坐标`[101.4,-40,265]`；完成板中心为`[102.2,0,290]`，器件朝+X。轴映射见配置及几何记录，独立预览未叠加整机3.7mm全局升高。外形仍在前轮`[97.4,-40,265]…[116.6,40,315]`预留内；对同一放置的静态空间可继承其包含关系，不能因此继承固定、线束、工具或连续运动资格。

封装之间当前输入模型的最小距离约0.8mm；部分使用名义尺寸，电容使用最大安装尺寸，这不是全部零件最坏公差下的制造间隙。45件有有效实体和闭合quad采样；quad采样不是细分曲面控制笼。采购件包络不导出为可打印替代器件。

PCB／无源件／连接器实际质量尚未闭合。`main_protection`的93g预留完整保留，未由包络体积估算质量，也未搬动旧SI中预留的位置。安装板525件候选的条件质量仍为10.486951740kg；本板不是新的整机质量冻结。

当前关键退出条件是：准确无源件及端子选型、封装复核与板厂工艺、实际功率路径和散热、冷启动及故障／急停使能链、真实固定和线束，然后合并完整质量／惯量并重跑受影响的整机检查。前轮预偏置理想制动仿真不能证明这些条件。装饰焊点和丝印细化可后置。

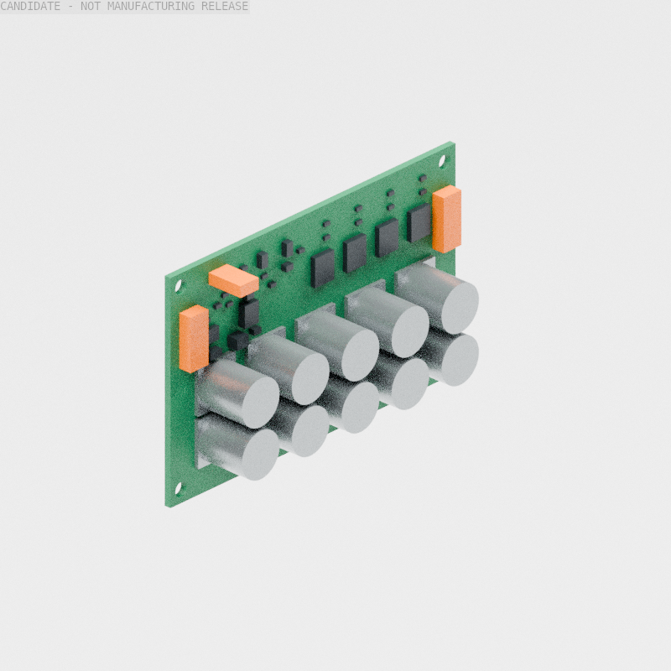
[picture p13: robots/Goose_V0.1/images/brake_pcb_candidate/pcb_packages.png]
实际包络渲染：不含走线或原厂器件细节


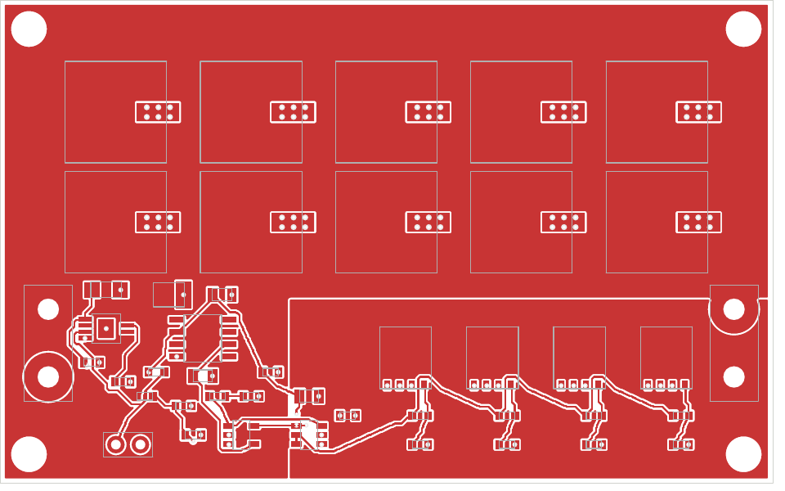
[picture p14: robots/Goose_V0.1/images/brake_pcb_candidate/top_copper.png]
KiCad原生顶层铜和器件轮廓


[顶层SVG](../images/brake_pcb_candidate/top_copper.svg)、[底层SVG](../images/brake_pcb_candidate/bottom_copper.svg)和[包络STEP](../cad/exports/brake_pcb_candidate/package_layout.step)均来自本版原生数据。

## 复现

从仓库根执行；需要兼容的pcbnew/KiCad CLI，以及CAD阶段的build123d/OCP、NumPy、SciPy、trimesh。本次原生工具为KiCad7.0.11，CAD运行时Python3.12；依赖运行时和厂商PDF保存在本地临时目录，未加入仓库。

```bash
PYTHONPATH=src python scripts/models/build_goose_brake_pcb.py --drc
PYTHONPATH=src python scripts/cad/build_goose_brake_pcb_envelope.py
PYTHONPATH=src python scripts/diagnostics/check_goose_brake_pcb.py --kicad-cli /path/to/kicad-cli
PYTHONPATH=src python -m pytest -q tests/test_goose_brake_pcb.py tests/test_goose_brake_chopper.py tests/test_goose_brake_packaging.py
```

本检查不向机器人发送命令。有限通过范围与仍未放行的整机项目见[Goose唯一入口](../README.md)。

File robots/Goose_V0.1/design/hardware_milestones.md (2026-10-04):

# 整机优先的硬件里程碑与 Sai_Lab 交接

用户要求继续采用“总—分—总”，控制局部探索时间，定期交付可检查的阶段成果；当大结构、体型、质量和预算基本稳定时，先交付训练基线，再继续制造细节。最终完整硬件目标不变，但不把它设为开始训练的前置条件。

本文件管理执行节奏。[工程交付基线](accepted_hardware_execution.md)保留最终验收要求；本文件没有把那些要求标成已通过。

## 当前整机交付状态（2026-10-04）

当前独立整机结构源是[手动翼形检修门检查点](manual_wing_service_checkpoint.md)：478显示对象、18主动轴、闭嘴19体参数、10.398672986kg条件质量，比460版少32.090g。六片修复壳及18件名义铰链/关闭五金已合回同版SI，19项针对性测试通过。最终外观与完整制造仍未放行；下面460、462、446、419件记录均保留其历史身份。

新增[制动安装比较](../hardware/brake_packaging_checkpoint.md)是独立525件候选：48件CAD、10.486951740kg条件质量，替换相应预留后增加88.279g。21个有限姿态与同版静力复查通过；PCB、热、线束／工具和连续扫掠仍待资格，不自动成为训练或制造默认版。螺钉头和转向占位的失败实体／配置保留，修正未减少髋部范围或修改运行碰撞过滤。

训练/游戏碰撞交接使用[11凸包唯一入口](task_proxy_11_v1.md)，已发布003独立运行包；其MuJoCo与独立Rapier的基础动力学和逐对过滤证据分别限定范围。55对内部组合仅9对相邻连接忽略，其余46对保留。没有因此修改真实CAD、采购或SI参数，也不等于Unity/Godot运行验收或整机制造完成。

[翼门几何拒绝记录](../evidence/wing_door_geometry_rejection.json)与[复现入口](../../../scripts/diagnostics/check_goose_wing_door_geometry.py)保留本轮的原始失败：当前右门与前固定壳在关闭位检出4.730269mm³交集；一个另建参数化门片试验虽然报告零交集，却与严格材料查询及独立采样网格的内点判断矛盾。另有旋转薄壳点查询把包围范围外的点判成材料内部。新增查询一致性检查拒绝这些结果，没有把试验门片合入装配，也没有把矛盾当成无干涉。

[身体曲壳自交修复检查点](torso_service_skin_checkpoint.md)进一步确认旧六片壳面均未通过原生自交检查；拓扑有效标记不能覆盖此缺陷。独立六片裸壳已通过原生/STEP/quad/STL门槛、四组关闭位≥0.5mm间隙与限定0–90°旋转距离界。该裸壳检查点仍保留其原范围；后续478版已补屋顶凸台、圆形颈部开口、双铰链和手拧关闭保持，完成24件CAD/交换、28有限开合、16支承配对及126静力筛查。447个已映射原生源通过、2个嘴壳超时未知、29显示对象待原生归属；连续开合、完整内部路径、壁厚与承力仍待资格。旧自交源不再作为制造配合通过依据。

| 主线 | 当前证据与下一退出条件 |
|---|---|
| 真实制造装配 | 固定壳支承和单件主头壳已有有限证据；翼门已有实际双铰链、轴向保持与手拧闭合，有限检查通过并合回SI。接缝/审美、连续扫掠、全域壁厚/局部强度、完整工具/线束路径继续验收；不靠碰撞过滤绕开 |
| 电源与驱动 | [精确AK48 V1.11电气资料及18轴端点](../hardware/power_release_checkpoint.md)已确认15–28V、插头与所选KV协议范围；[绝对阈值制动候选](../hardware/absolute_brake_chopper_checkpoint.md)已有可编辑KiCad、原生连接、角点和三组实际NGSPICE行为/故障对照。PCB热/时序、冷启动、完整断开/安装、制造线束及物理标定仍待闭合；由设计Agent查证，不要求用户查自己未选的SKU |
| 同版模型与任务 | 003基础准入不证明指定物全流程拾取、拖拽、转向或复杂地形。结构参数改变后另建同版模型与任务回归 |
| 后端接续 | MuJoCo和独立Rapier分别有本轮限定证据；Godot/Jolt、Unity、Bevy应用内的资格分别记录，不能互相继承 |

**整机完整工程交付、硬件硬冻结、三四阶段完整验收仍未完成。** 003保留原身份和验收记录；最终CAD/SI若有增量，发布具名替代/增量入口与差异，不能回改已冻结包来制造版本一致。

## 历史第三、第四阶段检查点

[四处固定壳支承检查点](torso_shell_mount_checkpoint.md)形成独立462对象、18轴、10.4408944kg条件候选，净增加36.198g。30件原生/名义五金、18个有限装配姿态、嘴尖20N／中部50N各63个同源静力工况通过；保留默认和446源。右膝余量约0.05054Nm，不能视为动态容量通过。翼门/锁扣/接缝、局部强度、驱动额定、供电和当前同版动力学仍未闭合，完整三、四阶段和训练放行继续未通过。下一段回整机关键路径，选型与供应商资料核实由设计Agent负责。

[头部闭合检查点](camera_head_closure_checkpoint.md)按用户反馈修正原生后缘台阶和相机前部缺口：独立446个显示对象、18轴、10.4046964kg条件质量，比419件版增加2.29248g。29件名义原生/五金、十个有限头部姿态、两组各63个同源静力工况、参数与采购表已核对；右膝静力最小余量约0.05944Nm。新版[四色图及近景](microduck_color_blocking_446_parts.md)已从同一装配渲染，审美验收待定。完整装配、制造和新训练放行仍未通过；局部头部修补在此收束，返回整机供电/驱动与装配关键路径。

默认装配见[整机机械与物理检查点](mechanical_integration_checkpoint.md)：344件、10.3578562kg条件质量、368行候选BOM、中立SI/参考及接触模型、实际quad源和四套同版配色已经保存。独立[前端夹取与连续动作候选](tip_grip_checkpoint.md)仅增加1.673g，19.9秒名义自由根流程已夹起地面50g样件、保持约73.7mm间隙、放回并回站；补入双脚承重前馈后碰地问题不再出现于本轮0.2mm阈值检查。颈根仍有6次连续力矩截断，严格控制门槛未过；完整装配、电气、实际硬件与跨引擎仍未闭合。**三、四阶段完整目标没有完成，原三小时时间盒已超时；训练硬冻结未宣布。** 下一段回到整机装配和电源/驱动，不围绕局部截断或PPO无限迭代。

[419件整机候选](integrated_hardware_candidate.md)合并前端夹持、相机、电源与计算板固定件：18轴、10.4024039kg条件质量、19体完整静力惯量。嘴尖20N／中部50N各63个静力工况通过，嘴尖50N超载失败保留；右膝余量约0.09Nm。没有生成同版新碰撞/动力学模型，接口与电源保护、机壳支承及真实连接器仍待收敛，不能作为新的训练放行。

[419件 MicroDuck 四色交付](microduck_color_blocking_419_parts.md)保留相机前部衔接空隙的旧源状态；最新待验收图使用上述446件修正源。344/314/292件及第一版被否决方案完整保留。之后每次外观交付继续给Cream、Graphite、Lavender、Sky四套同版图，核对其与装配的源身份。

[夹持组件](grip_cassette_candidate.md)名义几何和安装归属通过，但TPU插入/材料、强度、工具路径和预紧未放行。供电保护、相机/壳/翼门/线束、实际硬件控制、跨引擎与完整任务仍未完成；这些保持真实退出条件，不能把检查点替代验收。

[相机承力架及视野](camera_installation_checkpoint.md)已完成一轮有限原厂包络/自研CAD/实际轨迹检查，确认当前夹取动作存在上嘴遮挡和近焦缺口，另给出一组有限低头观察姿态。候选净增约3.762g、未合入默认模型，实际插头/五金/线束和标定未闭合。局部探索在该检查点收束，下一段返回整机装配与电源/驱动关键路径；不新增视觉训练或继续细雕面罩。

[当前18轴通信](../hardware/current_hybrid_control_checkpoint.md)已补入选定USB-CAN-A的固定20字节协议、AK V3封包、两条CAN与独立TTL调度和被动采集入口；软件与真实串口库PTY检查通过。未确认的实际电机档案不以通用演示值代填，供电、硬件急停／看门狗和实物延迟仍未放行。下一段返回整机供电保护选型及安装、整机装配路径。

## 最新 90 分钟阶段交付

最新入口：[第二阶段结构与物理参数](stage_two_parameter_handoff.md)。18 轴、名义 8.854kg；63 个静力工况、7 个电机包络姿态与5组低位往返通过各自限定检查。嘴改用额定模组和等曲柄连杆，中颈模组同步升级，保持主轴、外形和脚底轮廓。第一阶段独立文件/ZIP 保留。

**硬件硬冻结仍未通过**：准确 AK48 电压/回馈、实际保护硬件与封闭头壳持续夹力未闭合。可将明确版本交给 Sai_Lab 初训，但本轮变化已超第一阶段逐体预算，必须新建训练版本。PPO 不再扩训，细孔/焊点继续后置。

## 阶段与当前状态

| 阶段 | 阶段成果 | 退出条件 | 当前状态 |
|---|---|---|---|
| M0 外观与资料基线 | 已确认 fuller 源、渲染、原始资料、版本入口 | 用户确认外观；源可追溯 | 已完成，已发布 GitHub 草稿 PR #3 |
| M1 整机架构收敛 | 同版关节/尺寸、主要硬件架构、质量与预算区间、关键承力和活动包络 | 没有预计会改变整机比例或训练接口的未决项；见下方门槛 | 嘴/中颈驱动与条件机构筛查完成；供电、实物热能力和承力连接未闭合 |
| M2 Sai_Lab 阶段交接 | 同版模型、惯量/驱动区间、碰撞与限位、统一 SI 契约、任务和变更边界 | 可加载与基础物理检查通过，资料一致；明确可开始训练的范围 | 已给出独立第二阶段初训包；不等同硬件硬冻结 |
| M3 工程细化与整机回归 | 完整 CAD/STEP/STL、采购、接线、装配、控制和验证 | 依最终工程交付门槛验收 | M2 后继续；与训练反馈汇合 |

**仍不能宣告硬件硬冻结。** 体型、主要轴线和脚底保持，但电源保护、头部热管理可能改变分体质量与包络。交付明确候选版本，后续逐体比较超界即重发。

## M1 只解决四个整机问题

1. **身体里能装什么、怎么承力。** 电池、电源、驱动、计算、主框架、颈根和髋部以实际包络/明确预留放入同一装配；优先保留已确认外形，检修和线束要有路径。
2. **整条运动链是否有能力。** 嘴—头—颈—躯干—腿—脚采用同版质量和关节坐标，检查站立、单脚换重心、坐下够地、带 50 g 物体和拖拽的关键姿态。容量比较必须包含电机/减速的尺寸、质量和有效输出区间，不能只看堵转力矩。
3. **整机预算是否收敛。** 大质量件、执行器、电池和框架形成质量分组及重心区间；高成本件形成来源明确的价格范围。未选小件用显式预留，不虚填精确报价，也不靠无限加配重或大电机解决问题。
4. **训练接口会不会再变。** 确定关节数量、轴向、坐标、传动关系、动作范围和驱动参数边界；把未知项分成可在训练中随机化的参数，和会迫使改模型的大结构问题。

局部问题只有在改变上述四项结论时才留在关键路径。不能独立决定整机是否可行的内容，进入延期清单。

## 何时可以交给 Sai_Lab

交接前给用户一页明确判定，而非一句“应该没问题”：

- 版本化整机包：源几何/参数哈希一致，关节树、轴、限位、接触轮廓、尺寸和中立 SI 数据相互对应；MuJoCo 是物理检查/训练入口，不能覆盖 Godot/Jolt、Unity、Bevy 的中立本体。
- 每个主要刚体给出名义质量、重心、惯量及有依据的变化范围；说明制造细化后预计变化和已计入预留，避免假精确。
- 主要驱动方案和安装包络可实现，关键姿态不存在明确的负载缺口；未实测的热额定、摩擦、背隙、延迟用明确范围和实测门槛表示，不冒充实测值。
- 基础检查覆盖重力/静力、接触、关节方向、低位拾取的可达性及主要自碰撞；不要求交接前已经训练出成功步态。
- 给出预算范围、未决项、允许的后续变化和会触发重新交接的变化。

控制变更的工作规则：关节数量/轴向、传动方向、主要连杆长度、接触轮廓变动必须重发模型版本；质量、惯量、摩擦等只有落在已交接的随机化范围内才可继续沿用该训练基线。范围应由本机工程估算产生，不能先随意写一个“±10%”就声称结构稳定。

M1 达标时明确通知：“这一版的大结构已收敛，可以把这个版本交给 Sai_Lab 开始训练。”随后给出可下载/可拉取的确定版本、包清单和剩余风险；不要求用户自行从多个历史模型里挑选。

## 时间盒与阶段交付

- 以约 **60–90 分钟有效工程工作**为一次阶段检查点，产出可复现文件、通过/失败证据及下一步；这不是固定时刻的成功承诺，也不另建后台定时任务。
- 每次检查点回到整机，记录关键路径是否减少。不能只汇报增加了多少脚本、图片、孔位或文档。
- 单个非关键细节先给一轮约 **30 分钟**排查上限。仍未解决时，记录边界、预留和后续入口，返回主线；不递归延伸为更多细节任务。
- 对承力、执行器能力、重大碰撞这类关键问题，不能以“延期”掩盖失败。限定候选数量，比较结构性替代方案；会大改外观、重量或成本时，集中带具体对比与用户对齐。
- 每阶段保存独立版本并更新同一 GitHub 草稿 PR。阶段通过和最终交付通过分开报告。

## 当前清单

**正在推进：** 同版整机架构、颈/腿负载与主要执行器方案、关键动作空间、质量/成本预算。

**已保存的阶段增量：** [脚底分层及嘴部筛查](foot_support_and_beak_transmission.md)。脚底有六件四边面源、两片承力板 STEP 毛坯和几何核查；嘴部目录比较证明不能直接把占位当成传动。该增量可回溯，不再继续展开其细孔或齿形。

**可延期：** 装饰包边精细分件、紧固件逐孔优化、局部走线美化、焊点优化、表面纹理和非承力圆角。脚部毛坯的详细孔位也暂缓，先确定整机所需脚踝结构。

**不可跳过但先做系统级收敛：** 颈根和中段输出能力；单脚/低位姿态下腿部负载；嘴部力路径、质量上限和安装空间；电源峰值能力。具体齿轮齿形、联轴器细节等可以后续细化，但必须先有可信的总体方案和容量预留。

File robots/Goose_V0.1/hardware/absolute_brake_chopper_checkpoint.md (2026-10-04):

# 绝对阈值制动支路：可编辑电路与行为仿真检查点

2026-10-04。本轮把“绝对约26V阈值”推进为有具体器件、针脚、可编辑KiCad源及NGSPICE波形的独立比较候选。**不是PCB制造文件、可采购放行BOM或整机供电放行**。478件硬件源、质量惯量及003训练包未改变。

## 电路与来源

[候选配置](../configs/absolute_brake_chopper_candidate.json)保存46个引用、准确SKU、针脚/网络、7份原厂PDF哈希及未确认项；[KiCad 7源](absolute_brake_chopper/absolute_brake_chopper.kicad_sch)内嵌符号，打开不依赖额外符号库。[逐件候选清单](absolute_brake_chopper/candidate_bom.csv)保留未定SKU，不填造可采购状态。符号针脚类型暂为passive；原生解析和连通性核对不等于ERC通过，全部封装尚未放行。

| 功能 | 候选与原厂依据 | 本轮边界 |
|---|---|---|
| 母线自供5V | [TPS7A1650DGNR](https://www.ti.com/lit/ds/symlink/tps7a16.pdf)，固定5V版 | IN/EN连接急停断开后的电机BUS；固定版针2 DNC保持未连接；EP用编辑器pad9表示，不是宣称原厂给它编号9 |
| 2.5V基准 | [REF5025IDR](https://www.ti.com/lit/ds/symlink/ref50.pdf)，高等级 | 0.05%初始、3ppm/K；不混用标准等级AIDR；焊接漂移仍需核验 |
| 滞回检测 | [TLV3201DBVR](https://www.ti.com/lit/ds/symlink/tlv3201.pdf)，100k/10.7k/1.65M反馈 | 55ns规格要求5V、20mV输入过驱和15pF负载；器件内部滞回仅有典型值，不能补成最大值保证 |
| 栅极驱动 | [UCC27511DBVR](https://www.ti.com/lit/ds/symlink/ucc27511.pdf) | 按本型号1=VDD、2=OUTH、3=OUTL、4=GND、5=IN−、6=IN+；不套相近型号针脚 |
| 制动开关 | 4×[BSC027N06LS5](https://www.infineon.com/assets/row/public/documents/24/49/infineon-bsc027n06ls5-datasheet-en.pdf) | 栅极各自2.2Ω和100k下拉；4.5V下3.9mΩ，热倍率1.8为假设；电流共享、实际铜面积及开关损耗未资格 |
| 电阻支路 | 8×[LTO100F4R700FTE3](https://www.vishay.com/docs/50051/lto100.pdf)，4.7Ω±1%并联 | 100W要求25°C壳温，不能当自由空气额定；单次冷态脉冲曲线不能代替重复热资格；库存未确认 |
| 母线电容 | 10×[35SVPF120M](https://industrial.panasonic.com/cdbs/www-data/pdf/AAB8000/AAB8000COL88.pdf)，120µF/35V | 第33页4.4Arms条件100kHz/105°C，10–100kHz补正0.7；ESR18mΩ条件100–300kHz/20°C，不能自动用于所有频率和寿命阶段 |

支路位于独立断开器的**负载侧**：`BUS → 电阻组 → MOS开关 → GND`；检测器和驱动也从BUS取电。J3只提供BIAS_PG观察，尚未构成硬件启用链。此结构避免简单把制动供电一并切走；本轮行为模型仍采用预先建立的理想5V/2.5V，未证明真实冷启动、掉电恢复或故障状态。

## 已验证的范围

[角点比较](../evidence/absolute_brake_chopper_comparison.json)与[真实NGSPICE输出摘要](../evidence/absolute_brake_chopper_spice.json)分别保存，不把理想波形当成器件最大保证。

- 原生KiCad 7.0.11导出的13网络、128连接针脚与配置一致；DNC保持未连。17项测试覆盖错误基准等级、上游取电、反相/错误驱动针脚、MOS/电容极性、阈值反馈、重复引用、虚假放行以及独立节点方程求解。
- 名义开启26.016V、关闭25.713V。每个转换64个保守角点，包含声明的回流焊与内部滞回预留；开启25.698–26.323V、关闭25.404–26.035V。这两项预留及精密电阻SKU仍未由原厂或实板保证，因此不是资格区间。
- 按17轴未改的受控轴功率包络890.429W、初始最小960µF、独立ESR预留及假设5µs整链响应，加入20mV比较器过驱后比较峰值26.767V。保持28V下的要求预算约41.3µs，**实际最大响应仍未知**。50/100µs反例被拒绝。
- NGSPICE 42实际积分4ms：上游源在0.5ms断开、890.429W理想回馈从0.75ms开始；名义峰值26.0754V，单电阻断开26.0753V；关闭制动的反例约0.829ms越过28V。之后的高电压只是无器件损坏模型的拒绝轨迹，不能解释为硬件能承受81.6V。
- 波形能量平衡包含电容储能、制动电阻、Ron开关、ESR和检测分压耗能，相对误差小于1e−8。名义/单电阻断开中位开关频率约26.27/12.52kHz；理想均流单电容RMS约1.792/1.162A，小于相应0.7补正后的3.08A。实际ESR频谱、寿命、均流和温升未闭合。

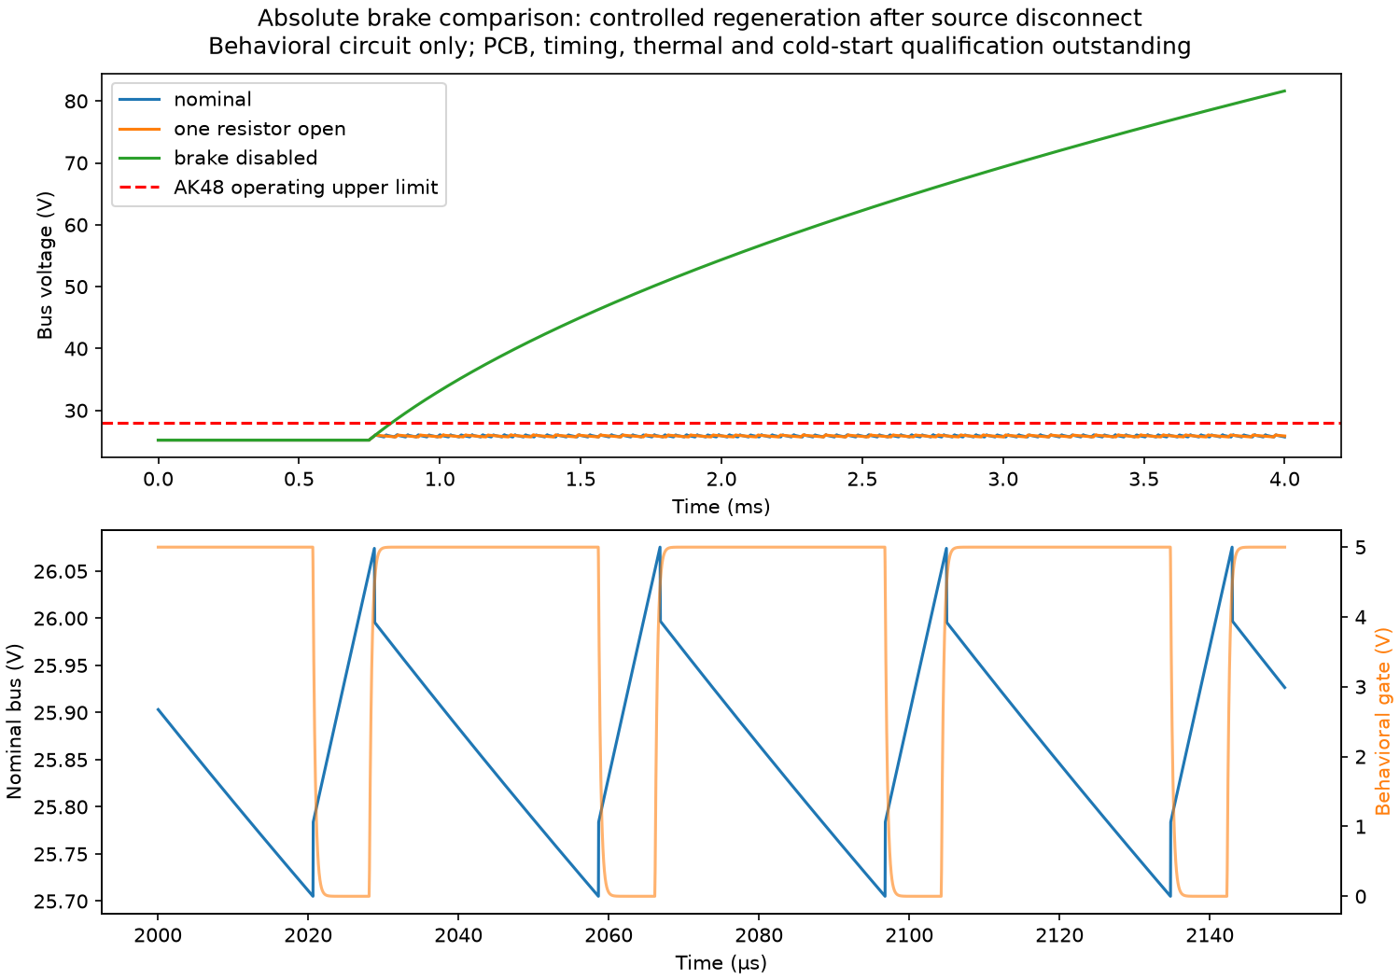
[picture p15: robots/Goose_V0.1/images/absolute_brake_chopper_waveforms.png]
NGSPICE母线与栅极行为波形


## 合回整机后的限制

当前478件账本有`main_protection`93g及`brake_hardware_extra_allocation`120g，共213g未闭合预留。120×80×6mm裸铝均热板按2700kg/m³为155.52g；8个电阻的原厂质量上界合计28g，比较组合183.52g，尚余29.48g供PCB、电容、其余元件、安装与线束。**这是库存预留对照，不是完整装机质量**；不得只抵扣其中一项，或把未资格散热板当最终散热器。没有据此更改整机质量与惯量。

468.769W连续负功率的理想均分约58.60W/电阻，按1.5K/W内部热阻需要壳温≤87.1°C；普通小铝板没有因此取得持续散热资格。0.1s峰值冷脉冲比较为11.13J/电阻，仍需按原厂脉冲曲线、初始温度和重复周期验收。本轮没有安装包络/固定/导热/气流源，因此不声明装得进机身。

下一整机退出条件：完成真实板件、线束/断开与冷启动路径、热/频率保证和安装固定后，替换账本预留并在同版装配复跑静力、干涉及接触回归。物理急停/看门狗保证、整机任务与跨应用引擎资格仍保留，不能由本电路局部通过覆盖。

后续独立增量见[制动安装检查点](brake_packaging_checkpoint.md)：已有48件原生CAD、独立同版SI及有限转向／低姿态和静力证据；这没有改写本电路的原始波形或替代PCB、热／线束／工具资格，也没有修改003训练包。

## 复现

使用Python项目依赖、KiCad 7及NGSPICE 42；生成物和连续波形留在忽略的`artifacts/`，原厂PDF不入库。以下命令从仓库根执行，均离线，不向电机发命令：

```bash
PYTHONPATH=src python scripts/models/build_goose_brake_chopper.py --spice-output artifacts/Goose_V0.1/brake_chopper_review/spice
kicad-cli sch export netlist --format kicadxml --output artifacts/Goose_V0.1/brake_chopper_review/circuit.xml robots/Goose_V0.1/hardware/absolute_brake_chopper/absolute_brake_chopper.kicad_sch
PYTHONPATH=src python scripts/models/build_goose_brake_chopper.py --native-netlist artifacts/Goose_V0.1/brake_chopper_review/circuit.xml --spice-output artifacts/Goose_V0.1/brake_chopper_review/spice
ngspice -b artifacts/Goose_V0.1/brake_chopper_review/spice/nominal.cir > artifacts/Goose_V0.1/brake_chopper_review/spice/nominal.log 2>&1
ngspice -b artifacts/Goose_V0.1/brake_chopper_review/spice/one_resistor_open.cir > artifacts/Goose_V0.1/brake_chopper_review/spice/one_resistor_open.log 2>&1
ngspice -b artifacts/Goose_V0.1/brake_chopper_review/spice/brake_disabled.cir > artifacts/Goose_V0.1/brake_chopper_review/spice/brake_disabled.log 2>&1
python scripts/diagnostics/check_goose_brake_chopper.py --directory artifacts/Goose_V0.1/brake_chopper_review/spice
PYTHONPATH=src python -m pytest -q tests/test_goose_brake_chopper.py
```

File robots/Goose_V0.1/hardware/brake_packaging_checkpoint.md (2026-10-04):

# 制动安装组：独立 CAD、质量与有限姿态检查点

2026-10-04。把绝对阈值制动电路中的8个电阻、安装板、紧固件和固定路径推进为48件可回读的原生CAD增量。**这仍是安装比较候选，不是完整PCB、散热或制造放行；没有替换478件基线或003训练包。**

| 表示 | 本轮身份与范围 |
|---|---|
| 保留的硬件基线 | 478显示对象，18主动轴，19体闭嘴SI，10.398672986kg条件质量 |
| 独立安装候选 | 525显示对象，18主动轴，19体闭嘴SI，10.486951740kg条件质量，增加88.279g |
| 实际CAD增量 | 48件：包含替换计算平台板、均热板、8个整件电阻、2个L支架和紧固件；原生BREP、STEP/STL和quad采样源 |
| 游戏／训练模型 | 仍是003的11个凸碰撞体、21动力学体、18主动轴；没有引入这些五金细节或改写旧SI |

## 安装与质量

[配置](../configs/brake_packaging_candidate.json)、[逐件源及交换记录](../cad/exports/brake_packaging/manifest.json)、[独立装配源](../cad/source/brake_packaging/assembly_scene.json)和[质量惯量账本](../evidence/brake_packaging_parameters.json)绑定同一父源。原生几何使用零位世界毫米；装配与SI统一加3.7mm全局升高，不能在旋转配合时重复加上。

120×80×6mm铝板竖放在机身内部，8个LTO100整件按两排、引脚朝外布置；两只L支架把它连接到保留的计算平台板。平台板仅另开两处3.2mm孔，旧源保留。电阻的3.5g原厂质量上界已经包含引脚，未重复计重。

首版3mm高的螺钉头只留1mm颈底净空，[失败实体与证据](../evidence/brake_packaging_socket_head_rejection.json)保留。平台改用[ISO7380 M3×12低头件的最大尺寸](https://www.accu.co.uk/socket-button-screws/494801-SSB-M3-12-10-9)，该处名义净空2.35mm。电阻使用[ISO7380-1 M3×16 A2低头件](https://www.accu.co.uk/socket-button-screws/8106-SSB-M3-16-A2)、M3垫圈和[DIN934 M3金属螺母](https://www.accu.co.uk/hexagon-nuts/7888-HPN-M3-A2)，取供应商最大头／螺母包络；国内供货、安装预紧和防松工艺仍未放行。防松胶是待资格工艺，不能拿产品温度范围当本连接的振动或热保证。

原先的左前部PCB预留会进入左髋转向空间，螺钉头也在髋偏航／侧摆角点触碰电机；[有限运动失败记录](../evidence/brake_motion_rejection.json)保留。新版安装组横向偏移1.5mm，板件预留改为机身前部的19.2×80×50mm竖向包络。没有缩小关节范围或套用仿真碰撞忽略。**这个框还不是PCB布局、安装设计或实际质量分布。**

48件合计302.611g，其中包含替换的平台板。仅抵扣旧平台板94.332g和制动安装预留120g；`main_protection`的93g电路／线束预留完整保留在原声明位置。因此新增质量88.279g，不能把空PCB框当已做出的器件，或把两个预留都无依据清空。

## 已通过的局部范围

[原生安装与静力证据](../evidence/brake_packaging_checks.json)检查48个新件、保留原生硬件、PCB及其余电子预留。旧平台板回读与公共体积证明只移除两孔材料，未扩大或隐藏原有零件。每个新增件通过原生自交／单实体、STEP和STL回读；quad采样闭合及体积误差门槛仍为0.5%。名义面接触和垫圈堆叠可要求零间隙，**仍拒绝正实体干涉**。自交集正对照与故意错放PCB的反例均用于检查查询能识别材料。

[运动净空证据](../evidence/brake_motion_clearance.json)覆盖21个不同有限姿态：零位、40／60／80度下蹲、低取、左右单脚支撑、左右及双髋±15度转向、各髋声明偏航／侧摆范围的四个角点。被动嘴部按保留契约的mimic运动，先核对主动轴位兼容与零位坐标恒等。所有样本通过2mm门槛，实际近对最小间隙约2.163mm。无原生CAD的保留显示／采购包络只在本检查内部构造保守凸包，**没有写回硬件源或运行碰撞模型**。这不是连续轨迹或完整任务资格。

同版质量／COM／完整惯量合回后，嘴尖20N和中段50N的两组各63例静力筛查通过，继续使用原有驱动限值及理想接触条件。质量增加而某些余量改善来自安装位置及账本估计范围变化，不意味着动态或热能力增加。实际连续额定、打印材料和完整接触任务仍另行资格。

下面两张来自本轮48件quad源，只显示安装组及替换平台板；没有把空PCB框画成实体电路：

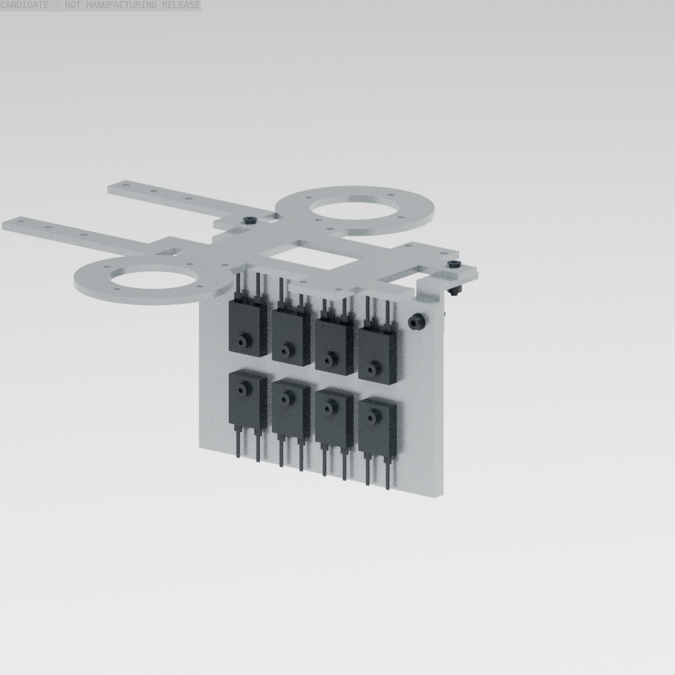
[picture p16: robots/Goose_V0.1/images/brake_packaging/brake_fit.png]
制动安装组前侧


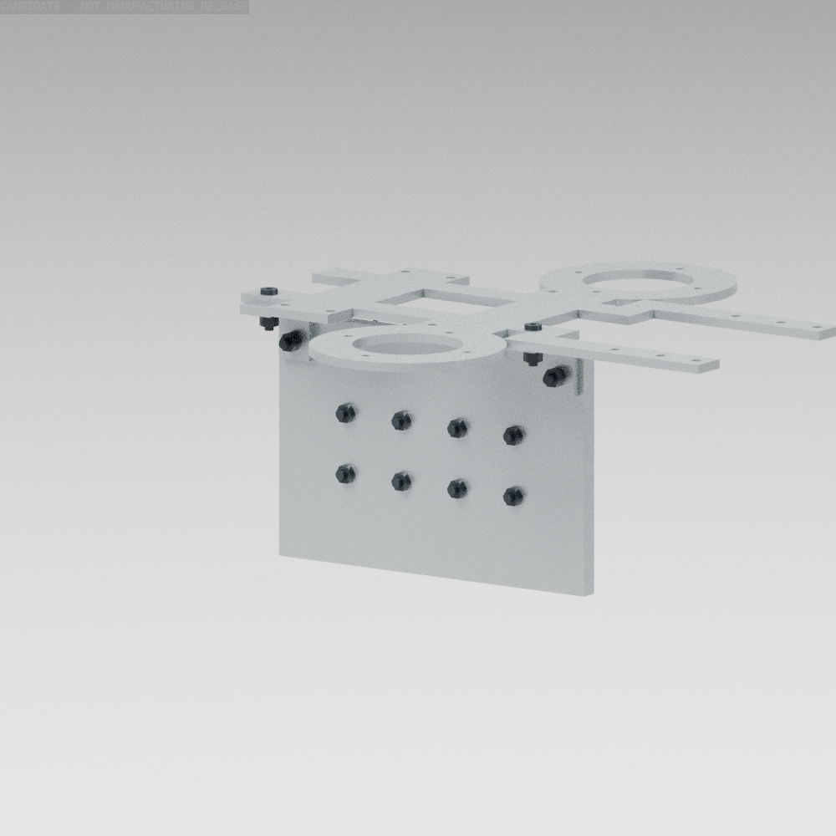
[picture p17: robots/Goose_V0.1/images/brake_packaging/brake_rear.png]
制动安装组后侧


## 后续退出条件与复现

实际PCB与元件、固定／连接器／弯线和检修工具路径、连续联合扫掠、散热与导热接触、防松／预紧工艺仍须闭合。原厂LTO100的壳温额定不代表这块小铝板能持续耗散468.769W；电路冷启动、断开器、最大整链响应、频谱／均流和实板热资格见[电路检查点](absolute_brake_chopper_checkpoint.md)。保留原模型的两处嘴壳完整性超时和未建组件缺口，不用本安装组局部通过覆盖整机问题。

以下命令从仓库根运行，使用build123d/OCP、NumPy、SciPy、trimesh、MuJoCo及Blender4.0；不向硬件发送命令：

```bash
PYTHONPATH=src python scripts/cad/build_goose_brake_packaging.py
PYTHONPATH=src python scripts/diagnostics/check_goose_brake_packaging.py
PYTHONPATH=src python scripts/diagnostics/check_goose_brake_motion_clearance.py
blender -b --factory-startup --python-exit-code 2 --python scripts/models/render_goose_brake_packaging.py -- --output artifacts/Goose_V0.1/brake_packaging_review/render
PYTHONPATH=src python -m pytest -q tests/test_goose_brake_packaging.py
```

渲染的PNG校验与源身份见[渲染记录](../evidence/brake_packaging_render.json)。安装候选的独立参数可供下一轮整机比较，未取得训练／制造／电气放行。

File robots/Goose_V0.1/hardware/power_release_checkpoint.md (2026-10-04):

# 当前电气检查点：精确驱动资料与18轴接线端点

2026-10-04 已取得精确 AK48 硬件与新版软件手册，补齐电压、接插件及所选型号的协议字段。当前18轴接线端点和条件回馈核算已可复现；新增[绝对阈值制动支路](absolute_brake_chopper_checkpoint.md)具有实际可编辑KiCad源、64角点/转换、原生连接核对和三组NGSPICE行为波形/故障对照。**PCB/热/完整断开与安装资格、制造线束及硬件启用仍未放行**。478件硬件候选、SI及003训练包均未因此改变。下文0.75Ω与相对阈值模块保留其比较身份，并非新增支路的选型。

## 已闭合的资料缺口

[原厂中文下载页](https://www.cubemars.com/cn/technical-support-and-software-download.html)包含有效的 AK48 安装说明和新版 V3 软件手册链接；同日英文页对应的 AK48 链接仍为空。不能把一个语言入口缺链接当成厂商没有资料。

[精确硬件手册](https://www.cubemars.com/data/cms/202609/ak48-2405-2d-a2-drive-installation-instructions-cn.pdf)第5、8、9页明确：AK48-2405-2D-A2 **V1.11**工作输入15–28V，名义24V；额定输出5Arms、最大10AP。这是驱动输出电流标签，不能当作直流母线电流或自行换算成Iq。第8页合并电源/CAN插头的板端配合视图如下，线端观察方向可能镜像，制作后仍须逐针导通核对。

| 插头 | 针1 | 针2 | 针3 | 针4 |
|---|---|---|---|---|
| 板端XT30PW(2+2)-M／线端XT30(2+2)-F | 电源正／红 | 电源负／黑 | CAN_L／蓝 | CAN_H／白 |
| XC330头部TTL，线端JST EHR-03 | GND | 独立5V | DATA | 无 |

AK48附带100±10mm线材：电源16AWG、CAN信号30AWG。这不是整机线束的长度或热验收。AMASS的[XT30(2+2)-F原厂规格](https://www.china-amass.net/uploads/71.XT30-2%2B2-F-SPEC-2025V0.pdf)为20A／16AWG／温升≤85K的测试条件，不能通过一个电机插头串接整机40A配电，也不能据此接受壳内85K温升。CAN信号沿线连接，电机电源独立星形分支。

[新版软件手册](https://www.cubemars.com/data/cms/202609/ak-series-motor-module-v3-driver-software-user-manual.pdf)第28页列出本机三个准确KV型号的MIT范围：

| 型号 | 速度字段rad/s | 转矩字段Nm | 名义输出Kt，Nm/Iq A |
|---|---:|---:|---:|
| AK40-10 V3.0 KV170 | ±45 | ±5 | 0.4894 |
| AK45-10 V3.0 KV75 | ±20 | ±8 | 1.1286 |
| AK45-36 V3.0 KV80 | ±6 | ±34 | 3.9790 |

三款位置字段均±12.56rad，Kp 0–500，Kd 0–5。17轴当前设计限值均在这些通信字段范围内；这不证明连续持力、实机标定或热能力。转矩字段±34Nm也不能覆盖电机本身峰值额定。现有MIT编码保持端点不回绕的保护，没有拿手册示例里其他型号的常数替换本机。物理`CommissionedAkProfile`仍要求实机身份、固件、位置/速度语义、零位、转矩标定及硬件超时证据；没有凭目录数据把未验证项设成true。

XC330-M288-T的[原厂范围](https://emanual.robotis.com/docs/en/dxl/x/xc330-m288/)是3.7–6.0V，建议5V，半双工TTL。它不能接主电机电压或CAN。[U2D2](https://emanual.robotis.com/docs/en/parts/interface/u2d2/)只提供通信，不向舵机供电；实际TTL接口与独立5V支路安装仍需完成。

全部来源、下载哈希、页码和适用性见[原厂事实表](ak48_v1_11_electrical_facts.json)。未将原厂PDF复制进仓库。此前[通用手册适用性记录](ak_manual_applicability_audit.json)保留历史身份；它对AK54/60/80的18–52V不能沿用到本机。

## 当前接线端点与复现

[18轴JSON](current_actuator_endpoints.json)／[CSV](current_actuator_endpoints.csv)绑定478件装配源和参数哈希。轴序、轴位、17个CAN轴的9/8分组及节点号均沿用原计划，另有独立5V头部轴。每条CAN物理线仅两端各120Ω；接线表不填造保险定值或全机线长，也没有向任何电机发送命令。

```mermaid
flowchart LR
  P[待资格：电池、浪涌、急停与回馈保护] --> M[受保护电机母线]
  M --> S[17路独立电源分支]
  S --> A[AK48 电源针1/2]
  U[主机／USB] --> CA[CAN A：9轴]
  U --> CB[CAN B：8轴]
  CA --> D[AK48 信号针3=L、4=H]
  CB --> D
  P --> V[独立受保护5V支路]
  V --> H[XC330 针1=GND、2=5V]
  U --> T[半双工TTL接口]
  T --> HD[XC330 针3=DATA]
```

离线复现：`PYTHONPATH=src python scripts/diagnostics/check_goose_electrical_endpoints.py`。精选[检查结果](../evidence/electrical_endpoint_and_brake_review.json)记录端点、型号协议范围和回馈假设。测试覆盖H/L互换、正负极接反、TTL误接24V、错轴/错节点、缺失/重复轴、错误端接及高电流串接等拒绝。

## 回馈稳态与瞬态分别验收

17轴受控轴功率包络仍为468.769W连续设计／890.429W峰值，按力矩限值×速度限值求和。为比较暂按100%进入母线，不假定电源能够吸收；它不覆盖失控机械动能、磁场储能、导线电感或实际电机损耗，350W正向机械限值也不限制负功率。

旧[回馈包络报告](../evidence/current_regeneration_envelope.json)要求电阻在20V低点便吸收全部功率，是充分条件而不是保持电压低于上限的必要条件。开启后的理想方程为`C·V·dV/dt=P−V²/R`，稳态为`V=sqrt(P·R)`。本轮用独立数值积分和能量守恒复查该修正，没有把旧拒绝报告覆盖掉。

以**未选型的比较值**0.75Ω±1%计算，890.429W下最坏理想稳态约25.971V；27.7V处最坏制动电流约37.306A，需按散热板条件比较，不能套用[ODrive Clamp](https://docs.odriverobotics.com/v/latest/hardware/regen-clamp-datasheet.html)自由空气20A条件。平均热功率、脉冲能量、安装温度和精确电阻SKU尚未闭合，因此没有列成可采购放行件。

6S满电25.2V加该模块最大2.50V触发偏移为27.7V，距AK48上限仅0.3V。声明外加2200µF、容差−20%、忽略ESR时，890.429W下从触发到28V仅约**16.5µs**；假设50µs延迟的理想电容电压已超过28V。再另留10mΩ ESR的保守瞬态裕量，当前条件无可用裕量。此ESR处理是独立保守预留，不是对厂商实际触发节点和波形的测量。

23V电源或绝对26V制动阈值能提供较大比较裕量，但仍只是要求场景；普通降压模块不自动吸收回馈，也没有由此更改电池、驱动或动作限值。厂商数据表没有给出最大响应延迟保证。**稳态算得下不等于瞬态通过；本轮没有放行6S+该相对阈值模块。**

下一退出条件是确定可证明的钳位/响应、断电吸能、浪涌/急停路径与实际器件，再把保护板、电阻、线束的真实质量和包络合回整机。闭合驱动额定与选型仍由设计Agent负责；[剩余问题稿](actuator_supplier_questions.md)已移除资料已明确的问题，未发送给任何人。实物温升与带载运动保留独立台架门槛。

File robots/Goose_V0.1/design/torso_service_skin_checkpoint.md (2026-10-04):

# 身体曲壳自交修复检查点

旧六片身体壳面虽然能通过拓扑有效、正体积与封闭网格检查，原生自交检查仍拒绝它们。此前门片的零交集读数与材料查询矛盾，不能当作配合通过。这里重建独立的六片裸壳，保留旧装配、旧参数和003运行包；**尚未替换当前460对象装配，也不是完整检修门或制造放行。**

## 修复范围

身体截面输入、名义2.4mm壁厚与轴位输入未改。旧坐标映射把门片经向宽度绑定到作者网格行，却同时让物理X随纬向变化，会带来后缘折返风险；仅平滑插值的尝试仍未解决原生自交拒绝。新映射把纬向特征绑定到物理X，用单调X映射生成身体曲面。直接在同一外、内原生曲面上裁剪固定壳与门片，不把裁剪后的采样点重新拟合成另一配合曲面。

曲面生成方式改变了下部出口和门沿几何，**不能继承旧装配、孔位、质量或动作资格**。原生自交通过只关闭该项输入缺陷，名义壁厚没有因此获得全域最小厚度证明。

| 资料 | 内容 |
|---|---|
| [结构输入](../configs/torso_service_skin.json) | UV裁剪、名义配合间隙、裸门片几何转轴与扫掠范围 |
| [CAD/STEP/STL清单](../cad/exports/torso_service_skin/manifest.json) | 六片原生、交换、全quad源、质量/完整惯量与哈希 |
| [显示源](../cad/source/torso_service_skin/quad_scene.json) | 六片CAD派生的封闭四边面；不含整机装配 |
| [原生配合与旋转距离界](../evidence/torso_service_skin_fit.json) | 原始拒绝、阳性对照、四组关闭配合和限定扫掠证明 |
| [原失败复现](../evidence/wing_door_geometry_rejection.json) | 4.730269mm³关闭位交集及查询矛盾，追加原生自交拒绝 |
| [源绑定检查图](../images/torso_service_skin_geometry.png) | 右侧三片实际quad源；不是最终外观图 |

六片均通过原生拓扑/小边/自交、STEP回读、封闭绕序与STL体积误差门槛。STL使用经过闭合/绕序/体积回读检查的binary32格式；精确编辑源继续使用BREP/STEP，quad源使用双精度坐标。没有靠修网格或扩大布尔容差获得通过。

## 当前证据

| 检查 | 结果与范围 |
|---|---|
| 旧六片原生自交 | 全部拒绝；与其拓扑有效标记分别保存 |
| 新六片原生及交换 | 六个源与STEP回读均通过独立自交检查；quad全部四边面并闭合；STL回读闭合且体积相对误差≤0.005 |
| 关闭位门片↔后固定壳 | 左、右各0交集；各最小距离0.675870769mm |
| 关闭位门片↔前固定壳 | 左、右各0交集；各最小距离0.879621395mm |
| Common阳性对照 | 两侧门片各与自身求交，恢复其原生体积，而非仅接受零值 |
| 裸壳几何旋转 | 左右各两组0–90°单轴旋转的距离下界通过，最低要求0.01mm；共128次中点距离查询 |
| 质量 | 六片裸壳按PETG1270kg/m³计算合计418.007438g；每片门31.796174g。屋顶安装凸台、真实铰链和锁止件尚未计入 |

转轴候选右侧Y−105/Z367mm，绕X负向旋转；左侧镜像并反向旋转。旋转检查对每个区间在中点测距，再扣除`2R sin(Δθ/4)`的全区间位移上界；R使用原生保守包围范围，距离对刚体位移的1-Lipschitz性质给出下界。区间不能满足下界则继续二分，达到预设最小区间仍失败，或耗尽每对128次查询预算，均拒绝。结果覆盖的只有**裸门片与同侧裸前、后壳**，没有实际铰链、内部零件或多轴整机运动。

13项针对性测试覆盖原生查询矛盾、真实旧壳自交拒绝、修复源、平面裁剪控制、封闭quad、旋转界的阳性/真实障碍阴性对照，以及现有相邻碰撞过滤。测试总数不替代上述限定范围。

## 下一整机退出条件

1. 保留本曲面基础，装回屋顶固定支承及实际颈部圆形开口，检查全域厚度、孔边与接缝支承。
2. 把几何转轴实现为有承力路径、轴向保持和实际五金的手动铰链，补可靠关闭保持；用真实零件复查闭合、开合与工具/线束路径。
3. 新零件与真实BOM合入独立整机装配，重建逐体质量、COM、完整惯量及同源静力，再给同版外观/动力学版本。

现有11凸包、9对相邻例外/46对保留和003运行包没有变化。几何修复不靠游戏碰撞过滤绕过制造干涉；头与躯干等非相邻碰撞继续保留。供电/驱动额定、完整任务与各后端验收仍是独立未完成项。

## 复现

需要build123d/OCP、NumPy、SciPy、trimesh；画图另需Matplotlib。本轮环境Python3.12.14、build123d0.11.1、OCP7.9.3.1。

```bash
env OPENBLAS_NUM_THREADS=1 PYTHONPATH=src .venv/bin/python scripts/cad/build_goose_torso_service_skin.py
env OPENBLAS_NUM_THREADS=1 PYTHONPATH=src .venv/bin/python scripts/diagnostics/check_goose_torso_service_skin.py
env OPENBLAS_NUM_THREADS=1 PYTHONPATH=src .venv/bin/python scripts/models/render_goose_torso_service_skin.py
env OPENBLAS_NUM_THREADS=1 PYTHONPATH=src .venv/bin/python -m pytest tests/test_native_cad_query_sanity.py tests/test_native_cad_skin_integrity.py tests/test_goose_collision_filters.py -q
```

原生检查使用已安装OCCT的`BRepAlgoAPI_Check`并开启小边与自交检查；[官方接口说明](https://www.occt3d.com/dev/doc/refman/html/class_b_rep_algo_a_p_i___check.html)与实际环境绑定的报告分别保留。所有通过项以该候选源及其报告哈希为准。

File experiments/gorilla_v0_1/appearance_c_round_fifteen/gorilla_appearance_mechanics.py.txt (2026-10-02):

"""Reference-shaped Gorilla C joints, articulated hands, and low broad shoes.

This module adds only editable appearance geometry.  The AA3 user-confirmed
four-view image is the reference; visible motor/barrel representations are not
SKU envelopes, physical mass estimates, or verified manufacturing assemblies.
Every color boundary below is an actual mesh boundary, never a reference image
projected onto a simpler model.  ``add_mechanics`` accepts the existing Geometry
builder and complete world-space point dictionary.
"""
from __future__ import annotations

import math

import numpy as np

def _unit(value):
    value = np.asarray(value, dtype=float)
    return value / np.linalg.norm(value)

def _radial_basis(axis):
    axis = _unit(axis)
    candidate = np.array([1.0, 0.0, 0.0])
    if abs(np.dot(axis, candidate)) > 0.9:
        candidate = np.array([0.0, 1.0, 0.0])
    first = _unit(candidate - axis * np.dot(axis, candidate))
    return axis, first, np.cross(axis, first)

def _lathe(g, name, body, center, axis, profile, color, *, n=48,
           hardware=True, note=""):
    """Closed solid of revolution, with beveled axial profiles and polygon caps."""
    axis, first, second = _radial_basis(axis)
    center = np.asarray(center, float)
    vertices = []
    for offset, radius in profile:
        for i in range(n):
            angle = 2.0 * math.pi * i / n
            vertices.append(center + axis * offset + radius * (
                first * math.cos(angle) + second * math.sin(angle)))
    faces = [list(reversed(range(n)))]
    for k in range(len(profile) - 1):
        for i in range(n):
            nxt = (i + 1) % n
            faces.append([k * n + i, k * n + nxt,
                          (k + 1) * n + nxt, (k + 1) * n + i])
    faces.append(list(range((len(profile) - 1) * n, len(profile) * n)))
    g.part(name, body, vertices, faces, color, hardware, note)

def _torus(g, name, body, center, axis, radius, radial_thickness,
           axial_thickness, color, *, n=64, m=8, hardware=True):
    """Thin closed ring.  Radial/axial tubes may differ, as in a machined lip."""
    axis, first, second = _radial_basis(axis)
    center = np.asarray(center, float)
    vertices = []
    for i in range(n):
        angle = 2.0 * math.pi * i / n
        radial = first * math.cos(angle) + second * math.sin(angle)
        for j in range(m):
            cross_angle = 2.0 * math.pi * j / m
            vertices.append(center + radial * (
                radius + radial_thickness * math.cos(cross_angle))
                + axis * axial_thickness * math.sin(cross_angle))
    faces = []
    for i in range(n):
        for j in range(m):
            faces.append([i * m + j, ((i + 1) % n) * m + j,
                          ((i + 1) % n) * m + (j + 1) % m,
                          i * m + (j + 1) % m])
    g.part(name, body, vertices, faces, color, hardware)

def _prism(g, name, body, center, u, v, normal, outline, depth,
           color, *, bevel=0.004, hardware=False, note=""):
    """Beveled closed prism in an arbitrary frame; outline is in local (u,v)."""
    center = np.asarray(center, float)
    u, v, normal = _unit(u), _unit(v), _unit(normal)
    outline = np.asarray(outline, float)
    centroid = outline.mean(axis=0)
    radius = np.linalg.norm(outline - centroid, axis=1)
    inset = centroid + (outline - centroid) * (
        1.0 - min(bevel / max(float(radius.min()), 1e-8), 0.23))
    bevel = min(bevel, depth * 0.35)
    layers = [(-depth / 2, inset), (-depth / 2 + bevel, outline),
              (depth / 2 - bevel, outline), (depth / 2, inset)]
    vertices = [center + p[0] * u + p[1] * v + z * normal
                for z, polygon in layers for p in polygon]
    n = len(outline)
    faces = [list(reversed(range(n)))]
    for k in range(3):
        for i in range(n):
            nxt = (i + 1) % n
            faces.append([k * n + i, k * n + nxt,
                          (k + 1) * n + nxt, (k + 1) * n + i])
    faces.append(list(range(3 * n, 4 * n)))
    g.part(name, body, vertices, faces, color, hardware, note)

def _rounded_rectangle(width, height, corner):
    x, y = width / 2, height / 2
    corner = min(corner, x * 0.7, y * 0.7)
    return [(-x + corner, -y), (x - corner, -y), (x, -y + corner),
            (x, y - corner), (x - corner, y), (-x + corner, y),
            (-x, y - corner), (-x, -y + corner)]

def _segment(g, name, body, start, end, depth, width, color,
             *, hardware=True, taper=0.84):
    """Finger/connector castings use chamfered sections, rather than capsules."""
    start, end = np.asarray(start, float), np.asarray(end, float)
    axis = _unit(end - start)
    cross_width = np.array([0.0, 1.0, 0.0])
    cross_width = _unit(cross_width - axis * np.dot(axis, cross_width))
    forward = _unit(np.cross(cross_width, axis))
    if forward[0] < 0:
        forward *= -1
    outline = np.array(_rounded_rectangle(depth, width, min(depth, width) * .18))
    vertices = []
    rings = [(0.0, .83), (.10, 1.0), (.82, taper), (1.0, taper * .83)]
    for t, scale in rings:
        center = start + t * (end - start)
        for x, y in outline * scale:
            vertices.append(center + forward * x + cross_width * y)
    n = len(outline)
    faces = [list(reversed(range(n)))]
    for k in range(len(rings) - 1):
        for i in range(n):
            nxt = (i + 1) % n
            faces.append([k*n+i, k*n+nxt, (k+1)*n+nxt, (k+1)*n+i])
    faces.append(list(range((len(rings)-1)*n, len(rings)*n)))
    g.part(name, body, vertices, faces, color, hardware)
    return axis, cross_width, forward

def _curved_casting(g, name, body, path, depth, width, color,
                    *, corner_ratio=.20, endpoint_scale=.84):
    """A continuous narrow chamfered casting following a short bent centerline."""
    path = np.asarray(path, float)
    outline = np.asarray(_rounded_rectangle(depth, width, min(depth, width)*corner_ratio))
    vertices = []
    previous_forward = None
    for i, center in enumerate(path):
        tangent = _unit(path[min(i+1, len(path)-1)] - path[max(i-1, 0)])
        cross_width = np.array([0.0, 1.0, 0.0])
        cross_width = _unit(cross_width - tangent*np.dot(tangent, cross_width))
        forward = _unit(np.cross(cross_width, tangent))
        if ((previous_forward is None and forward[0] < 0)
                or (previous_forward is not None and np.dot(forward,previous_forward) < 0)):
            forward *= -1
        previous_forward = forward
        scale = endpoint_scale if i in (0, len(path)-1) else 1.0
        vertices.extend(center + scale*(x*forward+y*cross_width) for x,y in outline)
    n = len(outline)
    faces = [list(reversed(range(n)))]
    for k in range(len(path)-1):
        for i in range(n):
            nxt = (i+1) % n
            faces.append([k*n+i, k*n+nxt, (k+1)*n+nxt, (k+1)*n+i])
    faces.append(list(range((len(path)-1)*n, len(path)*n)))
    g.part(name, body, vertices, faces, color, True,
           "Exposed bent casting reconstructed from the artwork joint gap; "
           "appearance only, not a hidden drive or a certified load-bearing part.")

def _leg_carrier(g,name,body,path,depth,width,color):
    """A broad round-shouldered arc, rather than a thin straight fork segment."""
    a,b,c=np.asarray(path,float)
    curve=[(1-t)**2*a+2*(1-t)*t*b+t*t*c for t in np.linspace(0,1,7)]
    _curved_casting(g,name,body,curve,depth,width,color,
        corner_ratio=.34,endpoint_scale=.88)

def _armor_edge_anchor(g, names, lower, y_target, fallback):
    """Pick a rearward vertex on the actual current shell end, not stale B depth."""
    matches = [np.asarray(p["vertices_world_m"], float)
               for p in g.parts if p["name"] in names]
    if not matches:
        return np.asarray(fallback, float)
    vertices = np.concatenate(matches)
    zmin, zmax = vertices[:,2].min(), vertices[:,2].max()
    band = min(.075, max(.035, .13*(zmax-zmin)))
    selected = vertices[vertices[:,2] <= zmin+band] if lower else vertices[vertices[:,2] >= zmax-band]
    # Rear side of the shell is where the artwork's dark fork disappears under
    # the armor.  Keep the two ears narrow and leave the central void open.
    selected = selected[selected[:,0] <= selected[:,0].min()+.045]
    cost = (selected[:,1]-y_target)**2 + .08*(selected[:,2]-(zmin if lower else zmax))**2
    anchor = selected[np.argmin(cost)].copy()
    anchor[0] += .007  # a small real overlap underneath the visible shell lip
    return anchor

def _section_properties(poly):
    """Exact area/centroidal planar inertia of a closed counterclockwise polygon."""
    q=np.asarray(poly,float);r=np.roll(q,-1,axis=0)
    c=q[:,0]*r[:,1]-r[:,0]*q[:,1];area=c.sum()/2
    if area<0:return _section_properties(q[::-1])
    cx=((q[:,0]+r[:,0])*c).sum()/(6*area)
    cy=((q[:,1]+r[:,1])*c).sum()/(6*area)
    iu=((q[:,1]**2+q[:,1]*r[:,1]+r[:,1]**2)*c).sum()/12-area*cy**2
    iv=((q[:,0]**2+q[:,0]*r[:,0]+r[:,0]**2)*c).sum()/12-area*cx**2
    iuv=((2*q[:,0]*q[:,1]+q[:,0]*r[:,1]+r[:,0]*q[:,1]+2*r[:,0]*r[:,1])*c).sum()/24-area*cx*cy
    return {"area_m2":float(area),"centroid_uv_m":[float(cx),float(cy)],
            "Iuu_m4":float(iu),"Ivv_m4":float(iv),"Iuv_m4":float(iuv)}

def _closed_box_member(g,name,body,start,end,depth,width,wall,color,role):
    """A straight finite-wall box member with genuine open bore, closed material.

    Both end sections, centerline and their local bases are emitted from the
    exact vertices. There is no side service cut and no hidden solid fill.
    """
    start,end=np.asarray(start,float),np.asarray(end,float)
    tangent=_unit(end-start)
    cross_width=np.array([1.,0.,0.]) if abs(tangent[1])>.95 else np.array([0.,1.,0.]);cross_width=_unit(cross_width-tangent*np.dot(tangent,cross_width))
    forward=_unit(np.cross(cross_width,tangent))
    if forward[0]<0:forward*=-1
    outer=np.asarray(_rounded_rectangle(depth,width,min(depth,width)*.14))
    # 8mm candidate wall at the flat walls; corner inset is the same thickness.
    inner=np.asarray(_rounded_rectangle(depth-2*wall,width-2*wall,max(.002,min(depth,width)*.14-(2-np.sqrt(2))*wall)))
    n=len(outer);rings=[start,end]
    vertices=[center+x*forward+y*cross_width for poly in (outer,inner) for center in rings for x,y in poly]
    off=2*n;faces=[]
    for i in range(n):
        j=(i+1)%n
        faces.extend([[i,j,n+j,n+i],[off+n+i,off+n+j,off+j,off+i],
                      [j,i,off+i,off+j],[n+i,n+j,off+n+j,off+n+i]])
    g.part(name,body,vertices,faces,color,True,
        "C14 closed-section primary frame candidate, 8mm nominal wall, no service window in the member. Actual material bore and end sections are modeled; root SI analysis/connection/clearance remains unverified.")
    a,b=_section_properties(outer),_section_properties(inner)
    section={k:a[k]-b[k] for k in ("area_m2","Iuu_m4","Ivv_m4","Iuv_m4")}
    g.parts[-1].update({"c14_primary_structure_segment":role,"nominal_wall_thickness_m":wall,
        "candidate_wall_parameter_range_m":[.006,.010],"section_outer_uv_m":outer.tolist(),"section_inner_uv_m":inner.tolist(),
        "exact_polygon_section_properties":section,"centerline_nodes_world_m":[start.tolist(),end.tolist()],
        "section_basis_forward_width_axis_world":[forward.tolist(),cross_width.tolist(),tangent.tolist()],
        "section_vertices_world_m":[np.asarray(vertices[:n]).tolist(),np.asarray(vertices[n:2*n]).tolist()],
        "physical_status":"Geometry/section candidate only; material, yield, buckling, joints, welds, fatigue and contact unverified."})
    # Exact root contract: u is the local width direction, v completes the
    # right-handed (axis,u,v) basis. Polygons are transformed from actual mesh.
    v_axis=_unit(np.cross(tangent,cross_width));sgn=float(np.dot(forward,v_axis))
    root_outer=np.column_stack([outer[:,1],outer[:,0]*sgn]);root_inner=np.column_stack([inner[:,1],inner[:,0]*sgn])
    ro,ri=_section_properties(root_outer),_section_properties(root_inner)
    root_section={k:ro[k]-ri[k] for k in ("area_m2","Iuu_m4","Ivv_m4","Iuv_m4")}
    root_section.update({"centroid_uv_m":[0.,0.],"median_enclosed_area_m2":_section_properties((root_outer+root_inner)/2)["area_m2"]})
    frame=[tangent.tolist(),cross_width.tolist(),v_axis.tolist()]
    g.parts[-1].update({"role":"primary_structure_candidate","structure_view_visible":True,
        "structural_member":{"id":name,"body":body,"distal_body":body,
        "centerline_world_m":[start.tolist(),end.tolist()],"station_basis_axis_u_v":[frame,frame],
        "outer_polygon_uv_m":root_outer.tolist(),"inner_polygon_uv_m":root_inner.tolist(),"wall_m":wall,
        "section":root_section,"perforations":False,
        "connections_status":"Common endpoint/socket and overlap envelope only; weld, flange, bearing, drive and load transfer unverified",
        "screen_scope":"Straight member with exact mesh-derived constant section; each bend is a separate member and unverified concentrated connection."}})

def _annular_joint_socket(g,name,body,center,outer_radius,inner_radius,length,color):
    """Finite annular shaft seat; no added axis or enlarged gold rim."""
    center=np.asarray(center,float);n=32;vertices=[]
    for rad in (outer_radius,inner_radius):
        for yy in (-length/2,length/2):
            for i in range(n):
                angle=2*math.pi*i/n;vertices.append(center+[rad*math.cos(angle),yy,rad*math.sin(angle)])
    faces=[];off=2*n
    for i in range(n):
        j=(i+1)%n
        faces.extend([[i,j,n+j,n+i],[off+n+i,off+n+j,off+j,off+i],
                      [j,i,off+i,off+j],[n+i,n+j,off+n+j,off+n+i]])
    g.part(name,body,vertices,faces,color,True,
        "C14 finite annular primary-frame shaft seat at the unchanged contract node. Original gold/visual bearing retained. Pin and force-transfer detail remains unverified.")
    g.parts[-1].update({"role":"primary_structure_socket_candidate","c14_joint_socket":True,"structure_view_visible":True,"joint_anchor_world_m":center.tolist(),
        "material_status":"Conditional steel density for stock mass only; bearing-seat material/yield, machining, journal fits and load transfer unverified",
        "candidate_outer_radius_m":outer_radius,"candidate_bore_radius_m":inner_radius,"candidate_axial_length_m":length})

def _leg_shell_connections(g,side,points,palette):
    """Complete hip-to-foot primary assembly, then independent cover interfaces.

    No black gap-filling walls. Constant-section straight members form the
    connected bent chain; every node/section is available to the root SI model.
    """
    s=1 if side=="left" else -1
    p={key:np.asarray(points[f"{side}_{key}"],float).copy() for key in ("hip","knee","fold","ankle","foot")}
    # Remove the previous separate thin ankle/heel links and saddles; the
    # complete closed-section foot cradle below supplies that same relationship.
    prefixes=(side+"_heel_link_",side+"_shoe_negative_y_heel_toe_low_saddle",side+"_shoe_positive_y_heel_toe_low_saddle")
    g.parts=[part for part in g.parts if not part["name"].startswith(prefixes)]
    chains={
        "thigh":([p["hip"],[.145,s*.357,1.370],[.122,s*.386,1.144],p["knee"]],.150,.180),
        "middle":([p["knee"],[-.012,s*.431,.853],[-.100,s*.455,.696],p["fold"]],.175,.180),
        "distal":([p["fold"],[-.165,s*.486,.406],p["ankle"]],.140,.168),
        "ankle_cradle":([p["ankle"],[p["ankle"][0],p["ankle"][1],.155],[p["ankle"][0],p["ankle"][1],.063]],.136,.196),
    }
    bodies={"thigh":side+"_thigh","middle":side+"_middle_shank","distal":side+"_distal_shank","ankle_cradle":side+"_foot"}
    for role,(nodes,depth,width) in chains.items():
        for i,(a,b) in enumerate(zip(nodes,nodes[1:])):
            _closed_box_member(g,side+f"_z_{role}_primary_box_{i}",bodies[role],a,b,depth,width,.008,palette["dark"],role)
    # A shared body chain lets the root assign upstream/downstream mass at
    # each short member without counting the entire body's own weight twice.
    body_paths={bodies[role]:[np.asarray(n,float).tolist() for n in data[0]]
                for role,data in chains.items()}
    for part in g.parts:
        member=part.get("structural_member")
        if member and member["body"] in body_paths:
            member["body_load_path_world_m"]=body_paths[member["body"]]
    # Broad low sole box carries the cradle into toe and independent high heel;
    # the low rails, toe shell, high heel and both rubber soles are unchanged.
    heel=[-.270,s*.600,.063];toe=[.380,s*.620,.063]
    sole_junction=[p["ankle"][0],s*.606,.063]
    for i,(a,b) in enumerate(zip((heel,sole_junction),(sole_junction,toe))):
        _closed_box_member(g,side+f"_z_foot_primary_sole_box_{i}",side+"_foot",a,b,.070,.404,.008,palette["dark"],"foot_base")
    # Short transverse closed foot base connects the real ankle node to the
    # broad sole centerline without dipping an inclined section below ground.
    _closed_box_member(g,side+"_z_foot_primary_crossbar",side+"_foot",
        [p["ankle"][0],p["ankle"][1],.063],[p["ankle"][0],s*.606,.063],
        .070,.166,.008,palette["dark"],"foot_base")
    for key,body,radius,bore,length in [
        ("hip",side+"_thigh",.102,.067,.232),
        ("knee",side+"_middle_shank",.102,.073,.252),
        ("fold",side+"_distal_shank",.100,.068,.242),
        ("ankle",side+"_foot",.097,.064,.248)]:
        _annular_joint_socket(g,side+"_z_"+key+"_primary_socket",body,p[key],radius,bore,length,palette["dark"])
    # The upper/lower rear guards sit on real short transverse mounting bars,
    # mechanically connected to the primary boxes, rather than unsupported tabs.
    for role,z,x,y,body in [("middle",.797,-.158,s*.446,side+"_middle_shank"),
                            ("distal",.409,-.225,s*.486,side+"_distal_shank")]:
        _closed_box_member(g,side+"_z_"+role+"_cover_mount_crossbar",body,
            [x,y-s*.074,z],[x-.008,y+s*.136,z],.073,.072,.008,palette["dark"],role)
    yellow=next((part for part in g.parts if part["name"]==side+"_yellow_front_knee_insert"),None)
    pad_x=p["knee"][0]+.399
    if yellow:
        v=np.asarray(yellow["vertices_world_m"]);low=v[(v[:,2]<=v[:,2].min()+.065)&(abs(v[:,1]-p["knee"][1])<=.100)]
        if len(low):pad_x=float(np.quantile(low[:,0],.66))-.023
    _prism(g,side+"_yellow_knee_notch_dark_pad",side+"_thigh",
        [pad_x,p["knee"][1],p["knee"][2]+.07322],[0,1,0],[0,0,1],[1,0,0],
        [(-.067,-.022),(.064,-.022),(.061,.020),(.047,.029),(-.051,.029),(-.067,.016)],
        .054,palette["dark"],bevel=.004,hardware=True,
        note="Original yellow-notch dark pad; independent cover interface, not a force-bearing certification.")
    _closed_box_member(g,side+"_z_knee_front_cover_support",side+"_thigh",
        [pad_x-.018,p["knee"][1],p["knee"][2]+.069],p["knee"]+[.026,0,.014],
        .066,.108,.008,palette["dark"],"thigh")
    foot_path=[p["ankle"].tolist(),[p["ankle"][0],p["ankle"][1],.155],
        [p["ankle"][0],p["ankle"][1],.063],sole_junction,list(toe)]
    body_paths[side+"_foot"]=foot_path
    for part in g.parts:
        member=part.get("structural_member")
        if member and member["body"] in body_paths:
            member["body_load_path_world_m"]=body_paths[member["body"]]
            member["native_vertex_layout"]="outer_station_0, outer_station_1, inner_station_0, inner_station_1; N=8"
            member["load_role"]="cover_mount_only_connection_unverified" if "cover_mount" in member["id"] or "cover_support" in member["id"] else "primary_body_chain_candidate"
            if member["body"]==side+"_foot":member["foot_branch_status"]="Heel/toe sole branches share the physical sole junction; branching reaction/load split is not solved by one body chain."

def _distal_ivory_guard(g,side,s,ankle,palette):
    """Thin returned ivory rear skin around the original lower-leg dark case."""
    scale=2.65/516.0
    outline=[(1026,510),(1037,516),(1031,533),(1021,544),(1016,547),(1005,539),(1011,525)]
    for direction,label in ((-1,"negative_y"),(1,"positive_y")):
        y=ankle[1]+direction*.152
        outside=np.array([[(971-u)*scale,y,(603-v)*scale] for u,v in outline])
        returned=outside.copy();returned[:,1]-=direction*.039;returned[:,0]+=.019
        n=len(outside);face=list(range(n))
        normal=sum((np.cross(outside[face[i]]-outside[0],outside[face[i+1]]-outside[0])
            for i in range(1,n-1)),start=np.zeros(3))
        outward=normal[1]*direction>=0
        if not outward:face.reverse()
        faces=[face]
        for i in (0,1,2,4):
            j=(i+1)%n
            faces.append([j,i,i+n,j+n] if outward else [i,j,j+n,i+n])
        g.cover(side+"_ivory_ankle_"+label+"_sloping_brace",side+"_distal_shank",
            np.concatenate([outside,returned]),faces,palette["ivory"],.007,
            note="Original long inclined ivory rear guard with inner skin and narrow returns around the separated dark lower-leg case; open mounting mouth, candidate thickness only.")

def _ankle_front_guard(g,side,s,ankle,body,ivory):
    """A curved short front ivory cover, nesting on the rear toe roof edge."""
    # A six-section transverse bow follows the exposed ankle/toe transition.
    profile=[(-.014,.260),(.060,.291),(.149,.303),(.219,.279),(.246,.244),(.218,.234)]
    widths=[.098,.106,.108,.108,.102,.093]
    vertices=[]
    for (x,z),width in zip(profile,widths):
        for t in (-1,-.72,0,.72,1):
            vertices.append([ankle[0]+x,ankle[1]+s*.041+t*width,z+.010*(1-t*t)])
    faces=[]
    for k in range(len(profile)-1):
        for j in range(4):
            faces.append([k*5+j,k*5+j+1,(k+1)*5+j+1,(k+1)*5+j])
    # Narrow side cheek skins share the bow's actual boundary; the mounting
    # mouth between its first/last sections remains open, never a filled box.
    faces.append([k*5 for k in range(len(profile))])
    faces.append([k*5+4 for k in reversed(range(len(profile)))])
    # Front-facing direction, actual material shell open on its mounting back.
    normal=np.cross(np.asarray(vertices[1])-vertices[0],np.asarray(vertices[6])-vertices[0])
    if normal[0]<0:faces=[list(reversed(f)) for f in faces]
    g.cover(side+"_ivory_ankle_front_cap",body,vertices,faces,ivory,.008,
        note="Thin bowed ivory ankle-front guard nesting against the sloping toe roof, open on its mounting back; independent of the axle housing and dark shoe support.")

def _leg_axle_group(g, side, joint_name, point, palette):
    """Different wide visible bridges fitted to the sole artwork whole leg.

    The mildly oblique end surfaces expose the original FRONT ellipses and
    LEFT circles.  This is editable casing geometry; no physical axis, drive,
    stiffness, or load capacity follows from these appearance offsets.
    """
    s = 1 if side == "left" else -1
    # (visible-center offset Y/Z, ring-center half span, shell / core radius)
    settings = {
        "knee": (.01035,.01822,.15407,.088,.078),
        "fold": (-.01293,.00922,.14123,.087,.073),
        "ankle": (.03411,-.00252,.14123,.085,.071),
    }
    shift_y,shift_z,half_span,radius,core_radius=settings[joint_name]
    center=np.asarray(point,float)+[0,s*shift_y,shift_z]
    body=side+"_"+{"knee":"middle_shank","fold":"distal_shank","ankle":"foot"}[joint_name]
    name=side+"_"+joint_name
    # A continuous broad bridge remains visible between the two side cheeks.
    # The shoulder steps are geometric changes in width, not extra ornaments.
    bridge_half=half_span-.016
    axis=np.array([0.0,1.0,0.0])
    _lathe(g,name+"_wide_inner_bridge",body,center,axis,
        [(-bridge_half,core_radius*.86),(-bridge_half+.018,core_radius*.96),
         (-bridge_half*.54,core_radius*.96),(-bridge_half*.46,core_radius),
         (bridge_half*.46,core_radius),(bridge_half*.54,core_radius*.96),
         (bridge_half-.018,core_radius*.96),(bridge_half,core_radius*.86)],
        palette["dark"])
    # Two broad dark shoulders keep the real gaps legible at whole-body scale.
    for direction,label in ((-1,"negative_y"),(1,"positive_y")):
        _lathe(g,name+"_"+label+"_bridge_shoulder",body,
            center+[0,direction*half_span*.52,0],axis,
            [(-.011,core_radius*.96),(-.007,radius*.97),
             (.007,radius*.97),(.011,core_radius*.96)],palette["dark"])
        normal=_unit([.35,direction*.93675,0])
        # FRONT artwork endpoints show a small height difference; the casing
        # face follows it while the contract joint point is unchanged.
        dz=direction*s*({"knee":.01798,"fold":.01027,"ankle":.00514}[joint_name])
        ring_center=center+[.005,direction*half_span,dz]
        cheek_center=ring_center-normal*.014
        _lathe(g,name+"_"+label+"_support_cheek",body,cheek_center,normal,
            [(-.020,radius*.76),(-.012,radius),
             (.010,radius),(.015,radius*.88)],palette["metal"],n=48,
            note="Wide end bearing seat following the source whole-leg silhouette; appearance only.")
        _lathe(g,name+"_"+label+"_recessed_face",body,
            ring_center-normal*.001,normal,
            [(-.0015,radius*.80),(.0015,radius*.80)],palette["dark"],n=48)
        _torus(g,name+"_"+label+"_thin_rim",body,ring_center,normal,
            radius*.79,.0033,.0020,palette["gold"],n=64,m=8)

def _thigh_outer_shell_cover(g, side, hip, palette):
    """The broad sloped dark patch partly hidden by the upper blue leg.

    The original FRONT locates it near u230/v293.  Its unseen attachment and
    internal mechanics are left unspecified; this is not another joint axis.
    """
    name=side+"_thigh_outer_sloped_cover"
    if any(part["name"].startswith(name) for part in g.parts):
        return
    s=1 if side=="left" else -1
    ring_center=np.asarray(hip,float)+[.105,s*.18045,-.06855]
    normal=_unit([.47,s*.83,.30])
    body=side+"_thigh"
    _lathe(g,name+"_dark_casing",body,ring_center-normal*.015,normal,
        [(-.017,.066),(-.011,.089),(.007,.094),(.016,.083)],
        palette["dark"],n=48,hardware=True,
        note="Visible broad oblique thigh casing reconstructed from the sole FRONT contour; no new physical axis.")
    _lathe(g,name+"_inset_face",body,ring_center-normal*.0015,normal,
        [(-.001,.074),(.001,.074)],palette["metal"],n=48)
    _torus(g,name+"_thin_source_lip",body,ring_center,normal,
        .077,.0027,.0014,palette["gold"],n=64,m=8)

def _bearing(g, name, body, center, radius, length, palette, *, gold=True):
    """Compact transverse bearing with ribbed barrel, recess, and thin gold lip."""
    center = np.asarray(center, float)
    dark, metal, black = (palette[k] for k in ("dark", "metal", "black"))
    axis = np.array([0.0, 1.0, 0.0])
    _lathe(g, name + "_inner_barrel", body, center, axis,
           [(-length*.48, radius*.73), (-length*.42, radius*.83),
            (length*.42, radius*.83), (length*.48, radius*.73)], dark)
    # Two restrained dark collars separate the support cheeks and shaft.  More
    # equally spaced bright ribs produced the rejected accordion-like first pass.
    band_color = [float(.7*a + .3*b) for a,b in zip(dark, metal)]
    for i, offset in enumerate((-.23, .23)):
        _lathe(g, name + f"_barrel_band_{i}", body,
               center + axis * offset * length, axis,
               [(-length*.066, radius*.80), (-length*.047, radius*.94),
                (length*.047, radius*.94), (length*.066, radius*.80)], band_color)
    for s, label in ((-1, "negative_y"), (1, "positive_y")):
        end = center + axis * s * length / 2
        _lathe(g, name + "_" + label + "_support_cheek", body, end, axis,
               [(-.013, radius*.77), (-.009, radius),
                (.009, radius), (.013, radius*.91)], dark)
        face = end + axis * s * .0135
        _lathe(g, name + "_" + label + "_recessed_face", body, face, axis,
               [(-.0025, radius*.81), (.0025, radius*.81)], black)
        # Ring is narrow, inset, and much smaller than the surrounding armor.
        _torus(g, name + "_" + label + "_thin_rim", body,
               face + axis * s * .001, axis, radius*.81, .0040, .0032,
               palette["gold"] if gold else metal)
        _lathe(g, name + "_" + label + "_central_cap", body,
               face + axis * s * .0035, axis,
               [(-.0017, radius*.65), (.0017, radius*.65)], dark)
        # Small concentric step is dark-on-dark, not an invented colored badge.
        _torus(g, name + "_" + label + "_cap_step", body,
               face + axis * s * .005, axis, radius*.55, .0014, .001,
               metal, n=48, m=6)

def _forward_elbow_cover(g, side, elbow, palette):
    """The small near-circular gold lip visible in the source FRONT elbow gap.

    This shallow +X-facing cover supplements the existing transverse casing.
    It remains within that casing's bounding envelope and represents no extra
    physical rotation axis, drive SKU, or inferred internal assembly.
    """
    elbow = np.asarray(elbow, float)
    body = side + "_forearm"
    axis = np.array([1.0,0.0,0.0])
    _lathe(g,side+"_elbow_forward_shallow_cover",body,
           elbow+[.068,0,0],axis,
           [(-.003,.053),(0.0,.064),(.011,.064),(.016,.058)],
           palette["dark"],n=48,hardware=True,
           note="Shallow front-facing cover matching the artwork elbow circle; "
                "appearance only, within the existing transverse casing bounds.")
    _lathe(g,side+"_elbow_forward_recessed_face",body,
           elbow+[.0815,0,0],axis,[(-.0015,.052),(.0015,.052)],
           palette["black"],n=48)
    _torus(g,side+"_elbow_forward_thin_gold_ring",body,
           elbow+[.083,0,0],axis,.055,.0028,.0015,
           palette["gold"],n=64,m=8)
    _lathe(g,side+"_elbow_forward_dark_center",body,
           elbow+[.0835,0,0],axis,[(-.001,.049),(.001,.049)],
           palette["dark"],n=48)

def _oblique_leg_covers(g, side, joint_name, center, radius, length, body, palette):
    """Shallow forward/outward cover lips at the existing transverse shaft ends.

    FRONT shows an ellipse at either side of the shaft, not a new center pivot.
    These casing surfaces stay inside the original bearing bounding envelope.
    """
    center = np.asarray(center,float)
    for direction,label in ((-1,"negative_y"),(1,"positive_y")):
        normal = _unit([.52,direction*.854,0])
        mount = center + [radius*.34,direction*length*.39,0]
        name = side+"_"+joint_name+"_"+label+"_oblique_cover"
        _lathe(g,name+"_shallow_cheek",body,mount,normal,
               [(-.007,radius*.58),(-.005,radius*.70),
                (.005,radius*.70),(.007,radius*.64)],
               palette["dark"],n=48,hardware=True,
               note="Artwork-shaped shallow oblique casing at a transverse shaft end; "
                    "no additional physical axis or internal drive asserted.")
        face = mount+normal*.0072
        _lathe(g,name+"_dark_recess",body,face,normal,
               [(-.001,radius*.55),(.001,radius*.55)],palette["black"],n=48)
        _torus(g,name+"_thin_gold_lip",body,face+normal*.0006,normal,
               radius*.58,.0034,.0017,palette["gold"],n=64,m=8)

def _link_casting(g, name, body, a, b, width, depth, palette):
    """Dark structural link with a narrower inset surface, visible between shells."""
    axis, cross_width, forward = _segment(
        g, name + "_frame", body, a, b, depth, width, palette["dark"],
        hardware=True, taper=.93)
    middle = (np.asarray(a) + np.asarray(b)) / 2 + forward * (depth/2 + .001)
    _prism(g, name + "_recess", body, middle, cross_width, axis, forward,
           _rounded_rectangle(width*.52, np.linalg.norm(np.asarray(b)-a)*.64, .007),
           .004, palette["black"], bevel=.001, hardware=True)

def _hands(g, side, s, points, palette):
    wrist, palm = (np.asarray(points[f"{side}_{key}"], float)
                   for key in ("wrist", "palm"))
    body = side + "_palm"
    ivory, dark, black, metal = (palette[k] for k in ("ivory", "dark", "black", "metal"))
    # A narrow cuff and separated palm cover preserve exposed black wrist parts.
    _bearing(g, side + "_wrist", body, wrist, .064, .128, palette, gold=False)
    # The bearing stays at the forearm's wrist anchor.  Only the palm/finger
    # appearance below is inclined, avoiding the previous 35 mm collar shift.
    first_part = len(g.parts)
    _prism(g, side + "_palm_inner_carrier", body,
           palm + [-.009, 0, -.021], [0, s, 0], [0, 0, 1], [1, 0, 0],
           [(-.062,-.077),(.060,-.072),(.080,-.045),(.080,.050),
            (.054,.097),(-.034,.095),(-.064,.040)],
           .082, dark, bevel=.006, hardware=True)
    # The source ivory guard lies toward the outer palm.  The inner hinges stay
    # visible; covering the full palm width made the previous mesh a white block.
    _prism(g, side + "_ivory_palm_dorsal", body,
           palm + [.046,0,0], [0,s,0], [0,0,1], [1,0,0],
           # The seven FRONT landmark points (155,369)..(144,382), expressed
           # relative to the reference palm and unrotated by the 18-degree rest
           # slant.  This preserves the high inner corner and lower outer tip.
           [(.0042,.1024),(-.0545,.1003),(-.0727,.0567),(-.0262,-.0202),
            (.0743,-.0469),(.1136,-.0018),(.0786,.0561)],
           .020, ivory, bevel=.003)
    g.parts[-1]["edge_bevel_m"] = .002
    for vertex in g.parts[-1]["vertices_world_m"]:
        u = s*(vertex[1]-palm[1])
        vertex[0] = round(vertex[0]+.007*max(0.0,1.0-((u-.030)/.072)**2),8)
    # The rear image also shows a substantial clipped ivory palm plate; a thin
    # horizontal stripe on a black carrier did not reproduce that color area.
    _prism(g, side + "_ivory_palm_reverse_cover", body,
           palm + [-.055,0,0], [0,s,0], [0,0,1], [1,0,0],
           [(.004,.092),(-.046,.091),(-.062,.052),(-.022,-.018),
            (.065,-.042),(.098,-.002),(.068,.050)],
           .018, ivory, bevel=.003)
    g.parts[-1]["edge_bevel_m"] = .002
    _prism(g, side + "_palm_lower_dark_seam", body,
           palm + [.056,s*.034,-.068], [0,s,0], [0,0,1], [1,0,0],
           _rounded_rectangle(.082,.005,.0012),.0025,black,
           bevel=.0007, hardware=True)
    # Two small exposed dark hinge hats correspond to the source hand's inner
    # edge.  They are casing details, not newly declared physical hand joints.
    for label,y,z,r in (("upper",-.030,.071,.020),("lower",-.041,-.042,.018)):
        _lathe(g,side+"_palm_"+label+"_exposed_hinge",body,
               palm+[.039,s*y,z],[1,0,0],
               [(-.004,r*.76),(-.002,r),(.006,r),(.010,r*.81)],
               dark,n=32)
    joints = {joint["name"]: joint for joint in g.spec["joints"]}
    # Three fingers, with one longest center finger and naturally curled tips.
    # Knuckle spacing is intentionally smaller than rejected B geometry.
    lengths = [(.083,.060),(.094,.067),(.086,.062)]
    for i, (upper_length, lower_length) in enumerate(lengths, start=1):
        proximal = joints[f"{side}_finger_{i}_proximal"]["child"]
        distal = joints[f"{side}_finger_{i}_distal"]["child"]
        y = s * (i - 2) * .061
        p = palm + [.018, y, -.086]
        d = p + [.021,-s*.007,-upper_length]
        end = d + [.049,-s*.040,-lower_length]
        _lathe(g, f"{side}_finger_{i}_root_joint", proximal, p, [0, 1, 0],
               [(-.024, .021), (-.018, .026), (.018, .026), (.024, .021)],
               dark, n=24)
        axis, width_axis, forward = _segment(g, f"{side}_finger_{i}_proximal_casting",
            proximal,p+[0,0,-.010],d,.061,.051,dark,hardware=True)
        # Ivory first phalanx plate spans the visible proximal back, with dark seams.
        pad_center = p + (d-p)*.47 + forward * .031
        _prism(g, f"{side}_finger_{i}_ivory_first_pad", proximal,
               pad_center, width_axis, axis, forward,
               _rounded_rectangle(.046,upper_length*.78,.006),
               .013,ivory,bevel=.0025)
        g.parts[-1]["edge_bevel_m"] = .0015
        _prism(g, f"{side}_finger_{i}_ivory_reverse_first_pad", proximal,
               p + (d-p)*.45 - forward*.030, width_axis, axis, forward,
               _rounded_rectangle(.043,upper_length*.67,.005),
               .011,ivory,bevel=.002)
        g.parts[-1]["edge_bevel_m"] = .0015
        # The lower black segment has a continuous slight bend, not a sharp hook.
        _lathe(g, f"{side}_finger_{i}_interphalangeal_joint", distal,
               d, width_axis, [(-.021, .021), (-.017, .025),
                               (.017, .025), (.021, .021)], metal, n=24)
        mid = d+(end-d)*.53+[-.005,s*.005,-.004]
        _curved_casting(g,f"{side}_finger_{i}_curved_distal",distal,
                       [d,mid,end],.055,.050,dark)
        # Small inset rubber contact surface is actual geometry on the inner side.
        tip_axis = _unit(end-d)
        tip_width = _unit(np.array([0, 1, 0]) - tip_axis * tip_axis[1])
        tip_forward = _unit(np.cross(tip_width, tip_axis))
        if tip_forward[0] < 0:
            tip_forward *= -1
        _prism(g, f"{side}_finger_{i}_tip_contact_pad", distal,
               d + (end-d)*.74 - tip_forward*.023,
               tip_width, tip_axis, tip_forward,
               _rounded_rectangle(.032, lower_length*.40, .005),
               .005, black, bevel=.001, hardware=True)
    thumb_proximal = joints[side + "_thumb_proximal"]["child"]
    thumb_distal = joints[side + "_thumb_distal"]["child"]
    p = palm + [.010, -s*.112, .039]
    d = p + [.023, -s*.040, -.078]
    end = d + [.043, s*.012, -.063]
    _prism(g, side + "_thumb_root_web", body,
           palm + [-.005, -s*.094, .021], [0, s, 0], [0, 0, 1], [1, 0, 0],
           [(-.047, -.051), (.029, -.045), (.034, .047),
            (-.002, .060), (-.038, .032)],
           .085, dark, bevel=.005, hardware=True)
    _lathe(g, side + "_thumb_root_pin", thumb_proximal, p, [1, 0, 0],
           [(-.036, .022), (-.029, .030), (.029, .030), (.036, .022)],
           metal, n=32)
    axis, width_axis, forward = _segment(g, side + "_thumb_proximal_casting",
        thumb_proximal, p, d, .062, .050, dark, hardware=True)
    _prism(g, side + "_thumb_ivory_first_pad", thumb_proximal,
           p + (d-p)*.48 + forward*.032, width_axis, axis, forward,
           _rounded_rectangle(.044,.074,.006),
           .014,ivory,bevel=.0025)
    g.parts[-1]["edge_bevel_m"] = .0015
    _lathe(g, side + "_thumb_middle_pin", thumb_distal, d, [1, 0, 0],
           [(-.027, .024), (.027, .024)], dark, n=24)
    _segment(g, side + "_thumb_black_terminal", thumb_distal,
             d, end, .054, .046, dark, hardware=True, taper=.72)
    # Source palm and fingers lean inward.  This neutral appearance transform
    # is applied to the actual meshes about the passed-in palm anchor, and does
    # not claim the engineering joint anchors have been correspondingly frozen.
    angle = math.radians(-s * 18.0)
    c, sn = math.cos(angle), math.sin(angle)
    inward_lean = np.array([[1.0, 0.0, 0.0], [0.0, c, -sn], [0.0, sn, c]])
    # The source LEFT sees a palm face and three ivory first phalanges.  A +X
    # palm normal made both edge-on there.  This is a complete hand rest pose,
    # not an added wrist axis.  Widen the visible rest plane before mirrored
    # 45-degree yaw, preserving FRONT palm/array span and the prior Z profile.
    yaw = math.radians(s * 45.0)
    cy, sy = math.cos(yaw), math.sin(yaw)
    yaw_rotation = np.array([[cy,-sy,0.0],[sy,cy,0.0],[0.0,0.0,1.0]])
    visible_width = np.diag([1.0,1.326,1.0])
    rotation = yaw_rotation @ visible_width @ inward_lean
    hand_origin = palm + [0.0,-s*.0306,0.0]
    for part in g.parts[first_part:]:
        vertices = np.asarray(part["vertices_world_m"], float)
        part["vertices_world_m"] = np.round(
            (vertices - palm) @ rotation.T + hand_origin, 8).tolist()
    for direction,label in ((-1,"negative_y"),(1,"positive_y")):
        a = wrist + [.012,direction*.045,-.025]
        b = hand_origin + rotation @ np.array([-.028,direction*.045,.066])
        _curved_casting(g,side+"_palm_wrist_"+label+"_short_neck",body,
                       [a,(a+b)/2+[.005,0,.006],b],.038,.028,dark)

def _shoe_loft(g, name, body, origin, rings, color, *, hardware=False):
    """Closed low shoe rings; each outline is a real edited top-view polygon."""
    origin = np.asarray(origin, float)
    vertices = []
    for z, outline in rings:
        vertices.extend(origin + [x, y, z] for x, y in outline)
    n = len(rings[0][1])
    if any(len(outline) != n for _, outline in rings):
        raise ValueError(name + ": shoe loft rings must share vertex count")
    faces = [list(reversed(range(n)))]
    for k in range(len(rings)-1):
        for i in range(n):
            nxt = (i+1) % n
            faces.append([k*n+i, k*n+nxt, (k+1)*n+nxt, (k+1)*n+i])
    faces.append(list(range((len(rings)-1)*n, len(rings)*n)))
    g.part(name, body, vertices, faces, color, hardware)

def _shoe_panel(g, name, body, origin, outline, bottom, top_function, color):
    """Foot panel with a sloped top, faceted perimeter, and finite panel thickness."""
    origin = np.asarray(origin, float)
    vertices = [origin + [x, y, bottom] for x, y in outline]
    vertices += [origin + [x, y, top_function(x, y)] for x, y in outline]
    n = len(outline)
    faces = [list(reversed(range(n))), list(range(n, 2*n))]
    faces += [[i, (i+1)%n, (i+1)%n+n, i+n] for i in range(n)]
    # A broad top is split around an interior point so that edited slopes don't
    # depend on arbitrary triangulation of a nonplanar n-gon in OBJ/Blender.
    middle = np.asarray(outline).mean(axis=0)
    vertices.append(origin + [middle[0], middle[1], top_function(*middle)])
    faces.pop(1)
    faces += [[n+i, n+(i+1)%n, 2*n] for i in range(n)]
    g.part(name, body, vertices, faces, color)

def _inset_guard_outline(outline, thickness):
    """Offset the actual polygon sides inward, retaining its corner sequence."""
    outline=np.asarray(outline,float)
    next_points=np.roll(outline,-1,axis=0)
    signed_area=.5*np.sum(outline[:,0]*next_points[:,1]
                          -outline[:,1]*next_points[:,0])
    # A visual taper at the artwork's narrow toe tip must not invert the inner
    # polygon.  Its nominal gauge is reduced locally before the mouth return.
    thickness=min(thickness,.25*float(np.ptp(outline,axis=0).min()))
    direction=1.0 if signed_area>0 else -1.0
    edges=next_points-outline
    normals=direction*np.column_stack((-edges[:,1],edges[:,0]))
    normals/=np.linalg.norm(normals,axis=1)[:,None]
    constants=np.sum(normals*outline,axis=1)+thickness
    inside=[]
    for i,p in enumerate(outline):
        previous=(i-1)%len(outline)
        matrix=np.array([normals[previous],normals[i]])
        if abs(np.linalg.det(matrix))<1e-8:
            inside.append(p+thickness*normals[i])
        else:
            inside.append(np.linalg.solve(matrix,[constants[previous],constants[i]]))
    inside=np.asarray(inside)
    steps=np.roll(inside,-1,axis=0)-inside
    turns=steps[:,0]*np.roll(steps,-1,axis=0)[:,1]-steps[:,1]*np.roll(steps,-1,axis=0)[:,0]
    if np.any(direction*turns < -1e-10):
        # Very small original bevel corners can disappear under an offset.
        # A centered contraction preserves their ordering and a positive mouth
        # instead of creating crossed faces or duplicate zero-length edges.
        center=outline.mean(0)
        scale=1-2*thickness/float(np.ptp(outline,axis=0).min())
        inside=center+scale*(outline-center)
    return inside

def _guard_material(g,name,body,outer,inner,color,thickness,open_side=None):
    """One closed material volume around an open underside, with a real cavity.

    Outer/inner surfaces, roof faces and the mouth return are joined.  There
    is no face sealing the air opening and no filled white interior block.
    Thickness is a visual construction parameter, not a released gauge.
    """
    outer,inner=np.asarray(outer,float),np.asarray(inner,float)
    if outer.shape!=inner.shape:
        raise ValueError(name+": shell rings must match")
    levels,n,_=outer.shape
    count=levels*n
    vertices=list(outer.reshape(-1,3))+list(inner.reshape(-1,3))
    vertices.extend([outer[-1].mean(0),inner[-1].mean(0)])
    faces=[]
    for k in range(levels-1):
        for i in range(n):
            j=(i+1)%n
            if i==open_side:
                continue
            face=[k*n+i,k*n+j,(k+1)*n+j,(k+1)*n+i]
            faces.append(face)
            faces.append([count+q for q in reversed(face)])
    for i in range(n):
        j=(i+1)%n
        # Finite return around the air opening: this joins material surfaces,
        # rather than closing the whole opening with a white polygon.
        if i!=open_side:
            faces.append([i,count+i,count+j,j])
        faces.append([(levels-1)*n+i,(levels-1)*n+j,2*count])
        faces.append([count+(levels-1)*n+j,count+(levels-1)*n+i,2*count+1])
    if open_side is not None:
        i=open_side;j=(i+1)%n
        for k in range(levels-1):
            a,b=k*n+i,(k+1)*n+i
            faces.append([a,count+a,count+b,b])
            a,b=k*n+j,(k+1)*n+j
            faces.append([a,b,count+b,count+a])
        a,b=(levels-1)*n+i,(levels-1)*n+j
        faces.append([b,a,count+a,count+b])
    g.part(name,body,vertices,faces,color,False,
        "Open-underside armor guard with editable inner skin and mouth return; "
        "visual construction thickness, not validated manufacturing or load capacity.")
    g.parts[-1].update({"appearance_construction":
        "open_underside_and_rear_guard_shell" if open_side is not None else "open_underside_guard_shell",
        "nominal_visual_wall_thickness_m":thickness,"cavity_surface_present":True,
        "thickness_is_physical_contract":False,"edge_bevel_m":.0015})

def _loft_guard_shell(g,name,body,origin,rings,color,thickness=.012,
                      *,open_side=None):
    origin=np.asarray(origin,float)
    bottom,top=float(rings[0][0]),float(rings[-1][0])
    outer=[];inner=[]
    for z,outline in rings:
        outline=np.asarray(outline,float)
        inside=_inset_guard_outline(outline,thickness)
        inner_z=z-thickness*(z-bottom)/max(top-bottom,1e-9)
        outer.append([origin+[x,y,z] for x,y in outline])
        inner.append([origin+[x,y,inner_z] for x,y in inside])
    _guard_material(g,name,body,outer,inner,color,thickness,open_side)

def _panel_guard_shell(g,name,body,origin,outline,bottom,top_function,color,
                       thickness=.010):
    origin=np.asarray(origin,float)
    outline=np.asarray(outline,float)
    inside=_inset_guard_outline(outline,thickness)
    outer=[[origin+[x,y,bottom] for x,y in outline],
           [origin+[x,y,top_function(x,y)] for x,y in outline]]
    inner=[[origin+[x,y,bottom] for x,y in inside],
           [origin+[x,y,top_function(x,y)-thickness] for x,y in inside]]
    _guard_material(g,name,body,outer,inner,color,thickness)

def _outline_scanline(outline, v, *, epsilon=.05):
    """Horizontal extent of a manually traced visible artwork polygon."""
    outline = np.asarray(outline,float)
    epsilon=min(epsilon,float(np.ptp(outline[:,1]))*.1)
    v = min(float(outline[:,1].max())-epsilon,
            max(float(outline[:,1].min())+epsilon,v))
    hits=[]
    for a,b in zip(outline,np.roll(outline,-1,axis=0)):
        if abs(float(b[1]-a[1])) < 1e-10:
            continue
        t=(v-a[1])/(b[1]-a[1])
        if 0 <= t <= 1:
            hits.append(float(a[0]+t*(b[0]-a[0])))
    return min(hits),max(hits)

def _artwork_upper_toe(g,side,s,origin,body,ivory):
    """A continuous sloping toe roof with short edge returns, open underneath.

    Original FRONT controls the widened outward toe; LEFT controls the sloped
    roof and narrow trailing end.  Uncalibrated views disagree by about 3 px
    at the crest, so the FRONT height is retained as an appearance candidate.
    """
    origin=np.asarray(origin,float)
    local=np.array([[.117,.100,.235],[.064,-.095,.235],[-.014,-.154,.128],
        [.375,-.083,.123],[.382,.270,.110],[.260,.203,.180]])
    local[:,1]*=s
    vertices=[origin+p for p in local]
    # A shaped roof has real diagonal broad faces; no stacked horizontal rings.
    n=len(local);faces=[[0,1,5],[1,2,3],[1,3,5],[3,4,5]]
    if s<0:faces=[list(reversed(f)) for f in faces]
    lower=[]
    for p in local:
        q=p.copy();q[2]=max(.080,min(.105,p[2]-.020));lower.append(origin+q)
    vertices.extend(lower)
    # Short toe/outer/inner lips, with the entire rear and underside left open.
    for i in (1,2,3,4,5):
        j=(i+1)%n
        face=[j,i,n+i,n+j]
        faces.append(face if s>0 else list(reversed(face)))
    g.cover(side+"_ivory_artwork_sloping_toe",body,vertices,faces,ivory,.009,
        note="One sloping ivory toe roof with thin side skins down to the independent low rails, avoiding an oversized triangular side window. Rear/underside remain open around the dark shoe frame; finite inner skin, no filled shoe block or released gauge.")
    g.parts[-1]["edge_bevel_m"] = .002

def _profile_low_rail(g,name,body,origin,outline,color):
    """Thin low rail with the actual LEFT flat, toe slope and clipped ends."""
    scale=2.65/516.0
    origin=np.asarray(origin,float)
    def local_x(u):
        return -.075+(986.0-u)*scale-origin[0]
    rear=local_x(967.0)
    clipped=[]
    for a,b in zip(outline,np.roll(outline,-1,axis=0)):
        a,b=np.asarray(a,float),np.asarray(b,float)
        if a[0]>=rear:
            clipped.append(a)
        if (a[0]>=rear)!=(b[0]>=rear):
            t=(rear-a[0])/(b[0]-a[0]);clipped.append(a+t*(b-a))
    # Put real vertices at the two slope changes instead of interpolating one
    # uniform roof plane across the full long rail.
    split=[]
    for a,b in zip(clipped,np.roll(clipped,-1,axis=0)):
        split.append(a)
        hits=[]
        for x in (local_x(912.0),local_x(887.0)):
            if min(a[0],b[0])+1e-9<x<max(a[0],b[0])-1e-9:
                t=(x-a[0])/(b[0]-a[0]);hits.append((t,a+t*(b-a)))
        split.extend(q for _,q in sorted(hits))
    top=np.asarray(split,float)
    bottom=top.copy()
    bottom[:,0]=np.minimum(bottom[:,0],local_x(884.0))
    top[:,0]=np.maximum(top[:,0],local_x(964.0))
    inner_bottom=_inset_guard_outline(bottom,.010)
    inner_top=_inset_guard_outline(top,.010)
    # u912--964 is the observed v580 plateau, then v582 at u887,
    # and the cut leading point u876,v591. Bottom remains v598.
    stations=[local_x(964.0),local_x(912.0),local_x(887.0),local_x(876.0)]
    heights=[(603.0-v)*scale for v in (580.0,580.0,582.0,591.0)]
    roof=lambda x:float(np.interp(x,stations,heights))
    zbase=(603.0-598.0)*scale
    outer=[[origin+[x,y,zbase] for x,y in bottom],
           [origin+[x,y,roof(x)] for x,y in top]]
    inner=[[origin+[x,y,zbase] for x,y in inner_bottom],
           [origin+[x,y,roof(x)-.010] for x,y in inner_top]]
    _guard_material(g,name,body,outer,inner,color,.010)
    g.parts[-1]["edge_bevel_m"]=.0025

def _heel_recess_within_skin(g,side,body,origin,black):
    """Recess the existing rear face inside the lowered heel, with real rim."""
    heel=g.parts[-1]
    vertices=np.asarray(heel["vertices_world_m"],float).tolist()
    # The eight-point heel's rear wall between z=.063 and z=.1555.
    face_index=next(i for i,f in enumerate(heel["faces"])
                    if set(f)=={8,15,16,23})
    wall=heel["faces"].pop(face_index)
    hole=[];inset=[]
    for index in wall:
        point=np.asarray(vertices[index],float)-origin
        z=.071 if point[2]<.10 else .147
        y=math.copysign(.165 if z<.10 else .130,point[1])
        x=-.455+(z-.063)*(.016/(.1555-.063))
        hole.append(len(vertices));vertices.append((origin+[x,y,z]).tolist())
        inset.append(len(vertices));vertices.append((origin+[x+.012,y,z]).tolist())
    for i in range(4):
        j=(i+1)%4
        heel["faces"].append([wall[i],wall[j],hole[j],hole[i]])
        heel["faces"].append([hole[i],hole[j],inset[j],inset[i]])
    heel["faces"].append(inset)
    heel["vertices_world_m"]=np.round(vertices,8).tolist()
    rear=np.asarray([vertices[i] for i in inset]);center=rear.mean(0)
    skin=center+(rear-center)*.985
    skin[:,0]-=.0007
    inside=skin.copy();inside[:,0]+=.003
    faces=[list(reversed(range(4))),list(range(4,8))]
    faces.extend([[i,(i+1)%4,(i+1)%4+4,i+4] for i in range(4)])
    g.part(side+"_heel_recessed_rear_face",body,np.concatenate([skin,inside]),
           faces,black,True,"Actual small inset rear panel within the heel recess; appearance only.")
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

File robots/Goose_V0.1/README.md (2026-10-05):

# Goose V0.1

一只幽默又实用的双足机器人鹅：长颈、嘴内夹持、手动翼形检修门。设计参考 Untitled Goose Game 与 MicroDuck；叼取和拖拽同等重要。

## 碰撞体优化交付

**当前版本：`goose_task_proxy_11_v1`，共11个凸碰撞体。**

| 你要找的内容 | 直接打开 | 文件内容 |
|---|---|---|
| **1. 碰撞体示意图** | [打开三视图 PNG](images/task_proxy_11_v1_colliders.png) | 下方同图：斜视、侧视、正视，以及11个碰撞体的颜色图例 |
| **2. 碰撞体文件** | [打开碰撞文件目录](models/task_proxy_11_v1/) · [装配模型 robot.xml](models/task_proxy_11_v1/robot.xml) | 11个OBJ凸包；XML定义位置与关节装配，native_plant.json保留原硬件参数 |

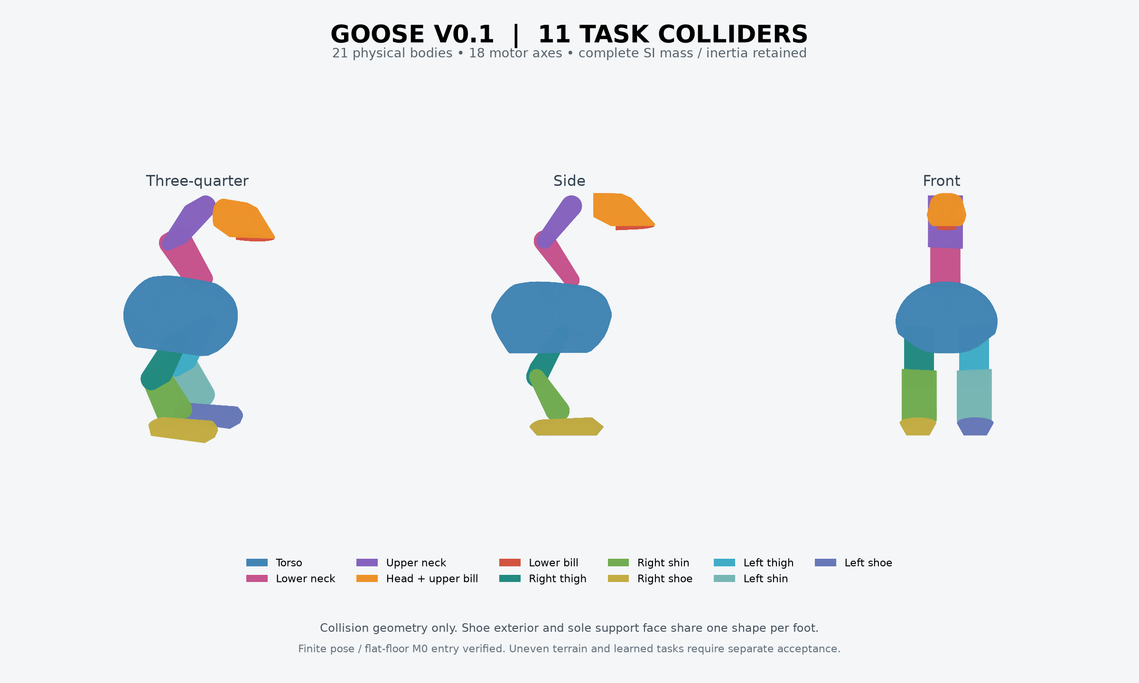
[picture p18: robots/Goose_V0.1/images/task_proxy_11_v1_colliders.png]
当前优化版：11个凸碰撞体三视图


取用时保留整个文件目录。OBJ以米为单位、使用所属刚体的局部坐标；组装位置以`robot.xml`为准。**这是仿真碰撞代理，真实硬件CAD与打印件另行保存。**

[逐个OBJ文件清单、运行契约与验证说明](design/task_proxy_11_v1.md)。

## 其他当前资料

| 内容 | 入口 |
|---|---|
| 外观、手动检修门与硬件结构候选 | [实际四色图、CAD及采购增量](design/manual_wing_service_checkpoint.md) |
| 电气与制动PCB候选 | [可编辑原理图、PCB与验证范围](hardware/brake_pcb_checkpoint.md) |
| 指定物训练输入 | [圆柱抓杆／把手，100／200／300g](design/task_samples_v1_handoff.md) |
| 虚拟训练版本与后续硬件差异 | [004冻结说明](design/virtual_training_freeze_handoff.md) |

硬件资料属于独立候选，未替换上述碰撞版本。平地工程入口、完整动作任务、各游戏引擎和实体制造分别验收；具体范围见各入口。

<details>
<summary>历史记录与原始导入资料</summary>

[历史记录与阶段候选](design/history_index.md)。旧模型、旧图、聊天交接和阶段试验集中从此页查阅，不作为当前碰撞交付入口。

</details>

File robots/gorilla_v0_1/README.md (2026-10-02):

# Gorilla V0.1

当前工作：**C15 复合脚阶段提交 → 内部完整模块预算与装配。** 先保存当前 Gorilla 外壳和分段脚候选，再闭合真实内部占位、宏观物理及载荷分摊。原稿形状仍是约束；最终目标是双足、双手和自主复杂 Bevy 任务。

唯一当前状态入口：[当前决定与门禁](design/current_decisions.md)。

| 资料 | 入口 |
|---|---|
| 唯一外观基准 | [用户再次确认的四视图](design/concepts/aa3/user_confirmed_four_view.jpg)；其他图片与粗模仅为历史资料 |
| 来源身份 | [唯一外观权威记录](source/appearance_authority.json)；[原包导入与哈希](source/appearance_import.json) |
| C 工作输入（迭代中） | [appearance_c_spec.json](configs/appearance_c_spec.json)；[原稿轮廓与分区点](source/appearance_c_reference_landmarks.json)；[可见护甲区域约束](source/appearance_c_front_shape_constraints.json) |
| C15 阶段基底 | [提交说明与缺口](design/appearance_c15_stage.md)；[冻结映射](../../experiments/gorilla_v0_1/appearance_c_round_fifteen/snapshot_manifest.json)；[Blender](../../experiments/gorilla_v0_1/appearance_c_round_fifteen/appearance_c.blend)、[GLB](../../experiments/gorilla_v0_1/appearance_c_round_fifteen/appearance_c.glb) |
| C15 实际复合脚 | [中立](../../experiments/gorilla_v0_1/appearance_c_round_fifteen/appearance_c_foot_left.png)、[卸载折叠](../../experiments/gorilla_v0_1/appearance_c_round_fifteen/appearance_c_foot_folded_left.png)、[机制拆壳](../../experiments/gorilla_v0_1/appearance_c_round_fifteen/appearance_c_foot_mechanism_left.png)；[原生几何检查](../../experiments/gorilla_v0_1/appearance_c_round_fifteen/composite_foot_c15_screen.json) |
| 内部研究输入 | [真实驱动/能源/热/感知模块依据](hardware/internal_module_research.md)；尚未完成整机模块布局 |
| 历史 C14 可编辑模型 | [Blender 源](../../experiments/gorilla_v0_1/appearance_c_round_fourteen/appearance_c.blend)、[GLB](../../experiments/gorilla_v0_1/appearance_c_round_fourteen/appearance_c.glb)、[参数化几何源](../../experiments/gorilla_v0_1/appearance_c_round_fourteen/appearance_c_scene.json)；外观/物理仍未通过 |
| 历史 C14 实际对照 | [同源四视](../../experiments/gorilla_v0_1/appearance_c_round_fourteen/appearance_c_four_view.png)；[阶段实渲审查](design/appearance_c_checkpoint_review.md)；[渲染身份](../../experiments/gorilla_v0_1/appearance_c_round_fourteen/appearance_c_render_manifest.json) |
| 内部主结构实渲 | [拆壳斜视](../../experiments/gorilla_v0_1/appearance_c_round_fourteen/appearance_c_structure_threequarter.png)、[正面](../../experiments/gorilla_v0_1/appearance_c_round_fourteen/appearance_c_structure_front.png)、[侧面](../../experiments/gorilla_v0_1/appearance_c_round_fourteen/appearance_c_structure_left.png)；同一实际几何，隐藏的护盖逐项记录 |
| 主体受力入口与结果 | [计算依据](design/structure_c14_basis.md)；[同版受力记录](../../experiments/gorilla_v0_1/appearance_c_round_fourteen/structure_c14_screen.json)、[红黄线](../../experiments/gorilla_v0_1/appearance_c_round_fourteen/structure_c14_gates.json)；有限准静力筛查，不是稳定动力学合同或吨级认证 |
| 当前工作树几何 | [可编辑控制网格](cad/source/appearance_c_scene.json)；后续增量须完成实渲/导出检查后才成为冻结候选 |
| C 外观增量与复现（历史） | [历轮冻结评审](design/appearance_c_checkpoint_review.md)；[当前 C14 冻结映射](../../experiments/gorilla_v0_1/appearance_c_round_fourteen/snapshot_manifest.json)（46 副本）；网格/文件身份通过，外观仍未通过 |
| 历史 C14 等高整机对照 | [正面](images/appearance_c_round_fourteen_front_comparison.png)、[侧面](images/appearance_c_round_fourteen_left_comparison.png)、[后面](images/appearance_c_round_fourteen_rear_comparison.png)；原图相机未校准，图像不能证明物理能力 |
| 用户新增背部控制屏 | [同版背屏近景](../../experiments/gorilla_v0_1/appearance_c_round_fourteen/appearance_c_rear_panel_detail.png)；原蓝板外框/固定点保留，状态/任务/本地控制为静态界面候选 |
| 散热入口原生几何复核 | [同版入口检查](../../experiments/gorilla_v0_1/appearance_c_round_fourteen/appearance_c_intake_clearance.json)；每侧 2008 个当前格栅间隙样本无蓝白甲遮挡，仅验证采样入口，不代表完整排风或热能力 |
| 持续排期与 PM | [滚动排期](design/project_schedule.md)；当前聊天每两小时检查实际产出 |
| 被否决的 B 与复现入口 | [layout_b_spec.json](configs/layout_b_spec.json)；[首轮候选评审](design/layout_b_checkpoint_review.md) |
| 历史 B 三维代理 | [四视图](images/layout_b_four_view.png)、[Blender 源](cad/source/layout_b.blend)、[GLB](cad/exports/layout_b/layout_b.glb)；仅作失败对照 |
| 历史 B 工程证据 | [SI 合同](models/full/robot.json)、[汇总](evidence/layout_b_checkpoint.json)、[质量账本](hardware/layout_b_mass_components.csv)、[静力与拒绝测试](evidence/layout_b_screen.json)；不代表 C |
| 历史尺寸探索参数 | [layout_a_spec.json](configs/layout_a_spec.json)；未生成模型，不能作为外观基准 |
| 任务与接口边界 | [任务和仿真交接](design/task_and_simulation_handoff.md) |
| 器件依据 | [驱动和供电参照](hardware/component_basis.md) |

首版核心为双足移动、双手操作、自主感知/规划/执行，最终在 Bevy 等游戏引擎的原生物理世界中完成搬运和环境操作。GD01 用于大型机器人方向参考；Goose 用于流程经验。两者的轴数、质量、尺寸、执行器和策略不继承。

C15 将前掌、足弓与后跟分开，取消跨段连续底板；卸载端姿态有界几何检查通过，固定侧止挡安装和锁止承力仍开放。尚未建立新脚 SI 合同，C14 整板脚的质量/接触/受力结果不适用于 C15。

历史 C14 已建立实际有限壁厚框架和条件质量/受力账本，包含当时脚底单向反力、关节六维载荷和限定截面应力。42 梁中 30 梁有有限筛查、12 梁未分析；条件毛料及组件预留总质量约 1.15–1.79 吨。完整惯量、轴向/驱动、连接/轴承/脚底、运动接触和热仍未闭合，外观也未放行。B 的失败记录保留，两版证据不混用；首个完整工程检查点仍未达标。

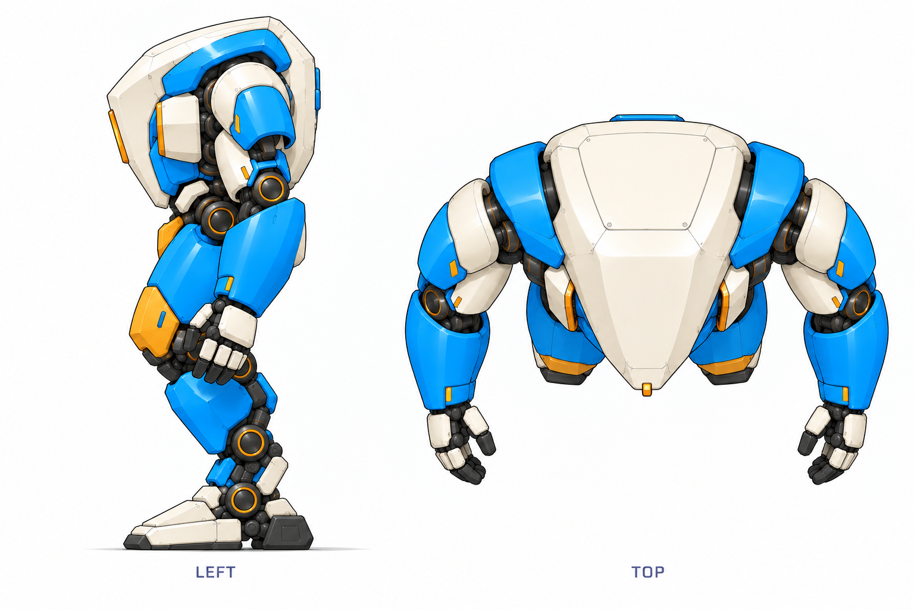
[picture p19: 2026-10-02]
robots/gorilla_v0_1/design/concepts/aa3/images/locked_machine_left_top_rev_aa2.png

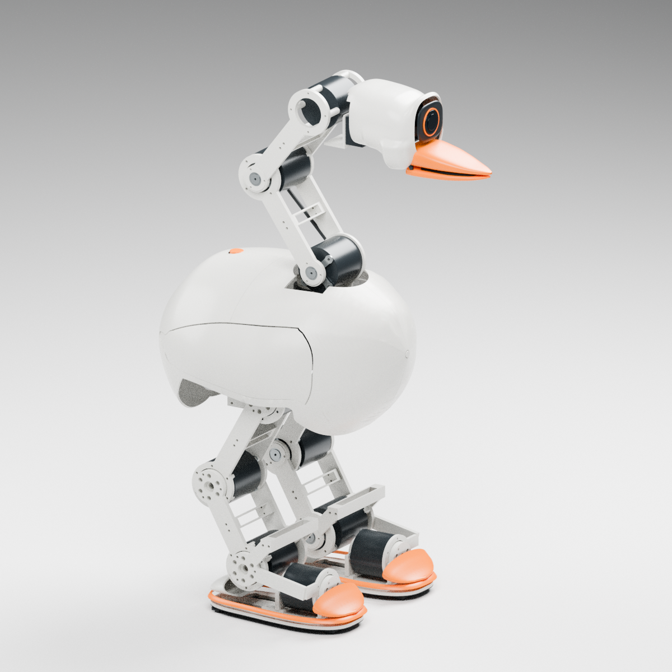
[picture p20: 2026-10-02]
robots/Goose_V0.1/images/mechanical_preview/three_quarter.png

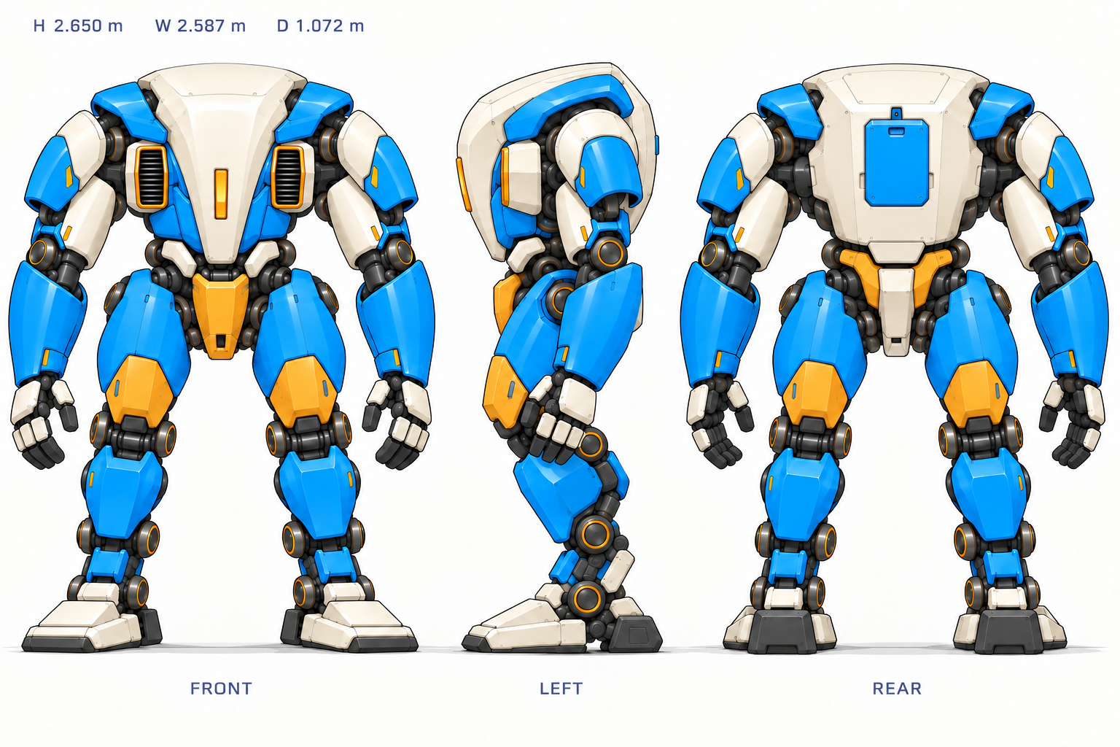
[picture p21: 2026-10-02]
robots/gorilla_v0_1/design/concepts/aa3/images/locked_front_rear_local_corrections_rev_aa1.png

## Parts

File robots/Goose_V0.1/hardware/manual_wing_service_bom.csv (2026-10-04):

part | quantity | sku | material | mass_kg | basis | primary_source | step | stl | manufacturing_release
wing_hinge_right_0_shoulder_screw | 1 | MISUMI MSB4.5-10 | SCM435 | 0.002238781834188124 | Own nominal purchased envelope, tolerances/price/delivery unqualified | https://sg.misumi-ec.com/vona2/detail/110300249140/?HissuCode=MSB4.5-10 | cad/exports/manual_wing_service/wing_hinge_right_0_shoulder_screw.step | cad/exports/manual_wing_service/wing_hinge_right_0_shoulder_screw.stl | False
wing_hinge_right_0_m3_washer | 1 | M3 plain washer OD7 ID3.2 t0.5mm | Steel | 0.00011948497879214389 | Nominal purchased envelope; confirm actual selected lot dimensions |  | cad/exports/manual_wing_service/wing_hinge_right_0_m3_washer.step | cad/exports/manual_wing_service/wing_hinge_right_0_m3_washer.stl | False
wing_hinge_right_0_retention_nut | 1 | KIPP 07214-203 DIN985 M3 | Steel+nylon | 0.0006684598402179003 | Own nominal maximum hex envelope; nylon mass is conservatively represented as steel | https://uk.c.misumi-ec.com/book/EPE1_ENG_09_10_24/pdf/1738.pdf | cad/exports/manual_wing_service/wing_hinge_right_0_retention_nut.step | cad/exports/manual_wing_service/wing_hinge_right_0_retention_nut.stl | False
wing_hinge_right_1_shoulder_screw | 1 | MISUMI MSB4.5-10 | SCM435 | 0.002238781834188124 | Own nominal purchased envelope, tolerances/price/delivery unqualified | https://sg.misumi-ec.com/vona2/detail/110300249140/?HissuCode=MSB4.5-10 | cad/exports/manual_wing_service/wing_hinge_right_1_shoulder_screw.step | cad/exports/manual_wing_service/wing_hinge_right_1_shoulder_screw.stl | False
wing_hinge_right_1_m3_washer | 1 | M3 plain washer OD7 ID3.2 t0.5mm | Steel | 0.00011948497879214389 | Nominal purchased envelope; confirm actual selected lot dimensions |  | cad/exports/manual_wing_service/wing_hinge_right_1_m3_washer.step | cad/exports/manual_wing_service/wing_hinge_right_1_m3_washer.stl | False
wing_hinge_right_1_retention_nut | 1 | KIPP 07214-203 DIN985 M3 | Steel+nylon | 0.0006684598402179003 | Own nominal maximum hex envelope; nylon mass is conservatively represented as steel | https://uk.c.misumi-ec.com/book/EPE1_ENG_09_10_24/pdf/1738.pdf | cad/exports/manual_wing_service/wing_hinge_right_1_retention_nut.step | cad/exports/manual_wing_service/wing_hinge_right_1_retention_nut.stl | False
wing_closure_right_thumb_screw | 1 | Elesa+Ganter DIN653-M3-8 blackened steel | Steel | 0.0026634422517134264 | Own nominal full-volume envelope, steel7850kg/m3; catalog rounded mass is not substituted | https://www.elesa-ganter.com/siteassets/PDF/EN/DIN%20653.pdf | cad/exports/manual_wing_service/wing_closure_right_thumb_screw.step | cad/exports/manual_wing_service/wing_closure_right_thumb_screw.stl | False
wing_closure_right_m3_washer | 1 | M3 plain washer OD7 ID3.2 t0.5mm | Steel | 0.000119484978792144 | Nominal purchased envelope; confirm actual selected lot dimensions |  | cad/exports/manual_wing_service/wing_closure_right_m3_washer.step | cad/exports/manual_wing_service/wing_closure_right_m3_washer.stl | False
wing_closure_right_m3_insert | 1 | Ruthex RX-M3x5.7 | Brass | 0.0005673633865576006 | Own nominal maximum-OD envelope; heat setting unqualified | https://www.ruthex.de/products/ruthex-gewindeeinsatz-m3-100-stuck-rx-m3x5-7 | cad/exports/manual_wing_service/wing_closure_right_m3_insert.step | cad/exports/manual_wing_service/wing_closure_right_m3_insert.stl | False
torso_manual_shell_right_aft | 1 | Self-designed PETG print candidate | PETG | 0.0866104492121238 | Full-density native CAD estimate, print unqualified |  | cad/exports/manual_wing_service/torso_manual_shell_right_aft.step | cad/exports/manual_wing_service/torso_manual_shell_right_aft.stl | False
torso_manual_shell_right_fore | 1 | Self-designed PETG print candidate | PETG | 0.09260513803195547 | Full-density native CAD estimate, print unqualified |  | cad/exports/manual_wing_service/torso_manual_shell_right_fore.step | cad/exports/manual_wing_service/torso_manual_shell_right_fore.stl | False
wing_manual_door_right | 1 | Self-designed PETG print candidate | PETG | 0.03417786948173991 | Full-density native CAD estimate, print unqualified |  | cad/exports/manual_wing_service/wing_manual_door_right.step | cad/exports/manual_wing_service/wing_manual_door_right.stl | False
wing_hinge_left_0_shoulder_screw | 1 | MISUMI MSB4.5-10 | SCM435 | 0.002238781834188124 | Own nominal purchased envelope, tolerances/price/delivery unqualified | https://sg.misumi-ec.com/vona2/detail/110300249140/?HissuCode=MSB4.5-10 | cad/exports/manual_wing_service/wing_hinge_left_0_shoulder_screw.step | cad/exports/manual_wing_service/wing_hinge_left_0_shoulder_screw.stl | False
wing_hinge_left_0_m3_washer | 1 | M3 plain washer OD7 ID3.2 t0.5mm | Steel | 0.00011948497879214389 | Nominal purchased envelope; confirm actual selected lot dimensions |  | cad/exports/manual_wing_service/wing_hinge_left_0_m3_washer.step | cad/exports/manual_wing_service/wing_hinge_left_0_m3_washer.stl | False
wing_hinge_left_0_retention_nut | 1 | KIPP 07214-203 DIN985 M3 | Steel+nylon | 0.0006684598402179003 | Own nominal maximum hex envelope; nylon mass is conservatively represented as steel | https://uk.c.misumi-ec.com/book/EPE1_ENG_09_10_24/pdf/1738.pdf | cad/exports/manual_wing_service/wing_hinge_left_0_retention_nut.step | cad/exports/manual_wing_service/wing_hinge_left_0_retention_nut.stl | False
wing_hinge_left_1_shoulder_screw | 1 | MISUMI MSB4.5-10 | SCM435 | 0.002238781834188124 | Own nominal purchased envelope, tolerances/price/delivery unqualified | https://sg.misumi-ec.com/vona2/detail/110300249140/?HissuCode=MSB4.5-10 | cad/exports/manual_wing_service/wing_hinge_left_1_shoulder_screw.step | cad/exports/manual_wing_service/wing_hinge_left_1_shoulder_screw.stl | False
wing_hinge_left_1_m3_washer | 1 | M3 plain washer OD7 ID3.2 t0.5mm | Steel | 0.00011948497879214389 | Nominal purchased envelope; confirm actual selected lot dimensions |  | cad/exports/manual_wing_service/wing_hinge_left_1_m3_washer.step | cad/exports/manual_wing_service/wing_hinge_left_1_m3_washer.stl | False
wing_hinge_left_1_retention_nut | 1 | KIPP 07214-203 DIN985 M3 | Steel+nylon | 0.0006684598402179003 | Own nominal maximum hex envelope; nylon mass is conservatively represented as steel | https://uk.c.misumi-ec.com/book/EPE1_ENG_09_10_24/pdf/1738.pdf | cad/exports/manual_wing_service/wing_hinge_left_1_retention_nut.step | cad/exports/manual_wing_service/wing_hinge_left_1_retention_nut.stl | False
wing_closure_left_thumb_screw | 1 | Elesa+Ganter DIN653-M3-8 blackened steel | Steel | 0.0026634422517134264 | Own nominal full-volume envelope, steel7850kg/m3; catalog rounded mass is not substituted | https://www.elesa-ganter.com/siteassets/PDF/EN/DIN%20653.pdf | cad/exports/manual_wing_service/wing_closure_left_thumb_screw.step | cad/exports/manual_wing_service/wing_closure_left_thumb_screw.stl | False
wing_closure_left_m3_washer | 1 | M3 plain washer OD7 ID3.2 t0.5mm | Steel | 0.00011948497879214412 | Nominal purchased envelope; confirm actual selected lot dimensions |  | cad/exports/manual_wing_service/wing_closure_left_m3_washer.step | cad/exports/manual_wing_service/wing_closure_left_m3_washer.stl | False
wing_closure_left_m3_insert | 1 | Ruthex RX-M3x5.7 | Brass | 0.0005673633865576007 | Own nominal maximum-OD envelope; heat setting unqualified | https://www.ruthex.de/products/ruthex-gewindeeinsatz-m3-100-stuck-rx-m3x5-7 | cad/exports/manual_wing_service/wing_closure_left_m3_insert.step | cad/exports/manual_wing_service/wing_closure_left_m3_insert.stl | False
torso_manual_shell_left_aft | 1 | Self-designed PETG print candidate | PETG | 0.08661044921212557 | Full-density native CAD estimate, print unqualified |  | cad/exports/manual_wing_service/torso_manual_shell_left_aft.step | cad/exports/manual_wing_service/torso_manual_shell_left_aft.stl | False
torso_manual_shell_left_fore | 1 | Self-designed PETG print candidate | PETG | 0.09260513807345563 | Full-density native CAD estimate, print unqualified |  | cad/exports/manual_wing_service/torso_manual_shell_left_fore.step | cad/exports/manual_wing_service/torso_manual_shell_left_fore.stl | False
wing_manual_door_left | 1 | Self-designed PETG print candidate | PETG | 0.034177869298511 | Full-density native CAD estimate, print unqualified |  | cad/exports/manual_wing_service/wing_manual_door_left.step | cad/exports/manual_wing_service/wing_manual_door_left.stl | False

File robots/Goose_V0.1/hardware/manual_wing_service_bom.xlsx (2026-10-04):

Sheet: hardware_delta
part | quantity | sku | material | mass_kg | basis | primary_source | step | stl | manufacturing_release
wing_hinge_right_0_shoulder_screw | 1 | MISUMI MSB4.5-10 | SCM435 | 0.002238781834 | Own nominal purchased envelope, tolerances/price/delivery unqualified | https://sg.misumi-ec.com/vona2/detail/110300249140/?HissuCode=MSB4.5-10 | cad/exports/manual_wing_service/wing_hinge_right_0_shoulder_screw.step | cad/exports/manual_wing_service/wing_hinge_right_0_shoulder_screw.stl | FALSE
wing_hinge_right_0_m3_washer | 1 | M3 plain washer OD7 ID3.2 t0.5mm | Steel | 0.0001194849788 | Nominal purchased envelope; confirm actual selected lot dimensions |  | cad/exports/manual_wing_service/wing_hinge_right_0_m3_washer.step | cad/exports/manual_wing_service/wing_hinge_right_0_m3_washer.stl | FALSE
wing_hinge_right_0_retention_nut | 1 | KIPP 07214-203 DIN985 M3 | Steel+nylon | 0.0006684598402 | Own nominal maximum hex envelope; nylon mass is conservatively represented as steel | https://uk.c.misumi-ec.com/book/EPE1_ENG_09_10_24/pdf/1738.pdf | cad/exports/manual_wing_service/wing_hinge_right_0_retention_nut.step | cad/exports/manual_wing_service/wing_hinge_right_0_retention_nut.stl | FALSE
wing_hinge_right_1_shoulder_screw | 1 | MISUMI MSB4.5-10 | SCM435 | 0.002238781834 | Own nominal purchased envelope, tolerances/price/delivery unqualified | https://sg.misumi-ec.com/vona2/detail/110300249140/?HissuCode=MSB4.5-10 | cad/exports/manual_wing_service/wing_hinge_right_1_shoulder_screw.step | cad/exports/manual_wing_service/wing_hinge_right_1_shoulder_screw.stl | FALSE
wing_hinge_right_1_m3_washer | 1 | M3 plain washer OD7 ID3.2 t0.5mm | Steel | 0.0001194849788 | Nominal purchased envelope; confirm actual selected lot dimensions |  | cad/exports/manual_wing_service/wing_hinge_right_1_m3_washer.step | cad/exports/manual_wing_service/wing_hinge_right_1_m3_washer.stl | FALSE
wing_hinge_right_1_retention_nut | 1 | KIPP 07214-203 DIN985 M3 | Steel+nylon | 0.0006684598402 | Own nominal maximum hex envelope; nylon mass is conservatively represented as steel | https://uk.c.misumi-ec.com/book/EPE1_ENG_09_10_24/pdf/1738.pdf | cad/exports/manual_wing_service/wing_hinge_right_1_retention_nut.step | cad/exports/manual_wing_service/wing_hinge_right_1_retention_nut.stl | FALSE
wing_closure_right_thumb_screw | 1 | Elesa+Ganter DIN653-M3-8 blackened steel | Steel | 0.002663442252 | Own nominal full-volume envelope, steel7850kg/m3; catalog rounded mass is not substituted | https://www.elesa-ganter.com/siteassets/PDF/EN/DIN%20653.pdf | cad/exports/manual_wing_service/wing_closure_right_thumb_screw.step | cad/exports/manual_wing_service/wing_closure_right_thumb_screw.stl | FALSE
wing_closure_right_m3_washer | 1 | M3 plain washer OD7 ID3.2 t0.5mm | Steel | 0.0001194849788 | Nominal purchased envelope; confirm actual selected lot dimensions |  | cad/exports/manual_wing_service/wing_closure_right_m3_washer.step | cad/exports/manual_wing_service/wing_closure_right_m3_washer.stl | FALSE
wing_closure_right_m3_insert | 1 | Ruthex RX-M3x5.7 | Brass | 0.0005673633866 | Own nominal maximum-OD envelope; heat setting unqualified | https://www.ruthex.de/products/ruthex-gewindeeinsatz-m3-100-stuck-rx-m3x5-7 | cad/exports/manual_wing_service/wing_closure_right_m3_insert.step | cad/exports/manual_wing_service/wing_closure_right_m3_insert.stl | FALSE
torso_manual_shell_right_aft | 1 | Self-designed PETG print candidate | PETG | 0.08661044921 | Full-density native CAD estimate, print unqualified |  | cad/exports/manual_wing_service/torso_manual_shell_right_aft.step | cad/exports/manual_wing_service/torso_manual_shell_right_aft.stl | FALSE
torso_manual_shell_right_fore | 1 | Self-designed PETG print candidate | PETG | 0.09260513803 | Full-density native CAD estimate, print unqualified |  | cad/exports/manual_wing_service/torso_manual_shell_right_fore.step | cad/exports/manual_wing_service/torso_manual_shell_right_fore.stl | FALSE
wing_manual_door_right | 1 | Self-designed PETG print candidate | PETG | 0.03417786948 | Full-density native CAD estimate, print unqualified |  | cad/exports/manual_wing_service/wing_manual_door_right.step | cad/exports/manual_wing_service/wing_manual_door_right.stl | FALSE
wing_hinge_left_0_shoulder_screw | 1 | MISUMI MSB4.5-10 | SCM435 | 0.002238781834 | Own nominal purchased envelope, tolerances/price/delivery unqualified | https://sg.misumi-ec.com/vona2/detail/110300249140/?HissuCode=MSB4.5-10 | cad/exports/manual_wing_service/wing_hinge_left_0_shoulder_screw.step | cad/exports/manual_wing_service/wing_hinge_left_0_shoulder_screw.stl | FALSE
wing_hinge_left_0_m3_washer | 1 | M3 plain washer OD7 ID3.2 t0.5mm | Steel | 0.0001194849788 | Nominal purchased envelope; confirm actual selected lot dimensions |  | cad/exports/manual_wing_service/wing_hinge_left_0_m3_washer.step | cad/exports/manual_wing_service/wing_hinge_left_0_m3_washer.stl | FALSE
wing_hinge_left_0_retention_nut | 1 | KIPP 07214-203 DIN985 M3 | Steel+nylon | 0.0006684598402 | Own nominal maximum hex envelope; nylon mass is conservatively represented as steel | https://uk.c.misumi-ec.com/book/EPE1_ENG_09_10_24/pdf/1738.pdf | cad/exports/manual_wing_service/wing_hinge_left_0_retention_nut.step | cad/exports/manual_wing_service/wing_hinge_left_0_retention_nut.stl | FALSE
wing_hinge_left_1_shoulder_screw | 1 | MISUMI MSB4.5-10 | SCM435 | 0.002238781834 | Own nominal purchased envelope, tolerances/price/delivery unqualified | https://sg.misumi-ec.com/vona2/detail/110300249140/?HissuCode=MSB4.5-10 | cad/exports/manual_wing_service/wing_hinge_left_1_shoulder_screw.step | cad/exports/manual_wing_service/wing_hinge_left_1_shoulder_screw.stl | FALSE
wing_hinge_left_1_m3_washer | 1 | M3 plain washer OD7 ID3.2 t0.5mm | Steel | 0.0001194849788 | Nominal purchased envelope; confirm actual selected lot dimensions |  | cad/exports/manual_wing_service/wing_hinge_left_1_m3_washer.step | cad/exports/manual_wing_service/wing_hinge_left_1_m3_washer.stl | FALSE
wing_hinge_left_1_retention_nut | 1 | KIPP 07214-203 DIN985 M3 | Steel+nylon | 0.0006684598402 | Own nominal maximum hex envelope; nylon mass is conservatively represented as steel | https://uk.c.misumi-ec.com/book/EPE1_ENG_09_10_24/pdf/1738.pdf | cad/exports/manual_wing_service/wing_hinge_left_1_retention_nut.step | cad/exports/manual_wing_service/wing_hinge_left_1_retention_nut.stl | FALSE
wing_closure_left_thumb_screw | 1 | Elesa+Ganter DIN653-M3-8 blackened steel | Steel | 0.002663442252 | Own nominal full-volume envelope, steel7850kg/m3; catalog rounded mass is not substituted | https://www.elesa-ganter.com/siteassets/PDF/EN/DIN%20653.pdf | cad/exports/manual_wing_service/wing_closure_left_thumb_screw.step | cad/exports/manual_wing_service/wing_closure_left_thumb_screw.stl | FALSE
wing_closure_left_m3_washer | 1 | M3 plain washer OD7 ID3.2 t0.5mm | Steel | 0.0001194849788 | Nominal purchased envelope; confirm actual selected lot dimensions |  | cad/exports/manual_wing_service/wing_closure_left_m3_washer.step | cad/exports/manual_wing_service/wing_closure_left_m3_washer.stl | FALSE
wing_closure_left_m3_insert | 1 | Ruthex RX-M3x5.7 | Brass | 0.0005673633866 | Own nominal maximum-OD envelope; heat setting unqualified | https://www.ruthex.de/products/ruthex-gewindeeinsatz-m3-100-stuck-rx-m3x5-7 | cad/exports/manual_wing_service/wing_closure_left_m3_insert.step | cad/exports/manual_wing_service/wing_closure_left_m3_insert.stl | FALSE
torso_manual_shell_left_aft | 1 | Self-designed PETG print candidate | PETG | 0.08661044921 | Full-density native CAD estimate, print unqualified |  | cad/exports/manual_wing_service/torso_manual_shell_left_aft.step | cad/exports/manual_wing_service/torso_manual_shell_left_aft.stl | FALSE
torso_manual_shell_left_fore | 1 | Self-designed PETG print candidate | PETG | 0.09260513807 | Full-density native CAD estimate, print unqualified |  | cad/exports/manual_wing_service/torso_manual_shell_left_fore.step | cad/exports/manual_wing_service/torso_manual_shell_left_fore.stl | FALSE
wing_manual_door_left | 1 | Self-designed PETG print candidate | PETG | 0.0341778693 | Full-density native CAD estimate, print unqualified |  | cad/exports/manual_wing_service/wing_manual_door_left.step | cad/exports/manual_wing_service/wing_manual_door_left.stl | FALSE

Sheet: neutral_si
body | mass_kg | com_x_m | com_y_m | com_z_m | ixx_kg_m2 | iyy_kg_m2 | izz_kg_m2 | ixy_kg_m2 | ixz_kg_m2 | iyz_kg_m2
torso | 2.182999572 | -0.014417886 | -0.001678063824 | 0.3320272139 | 0.008099295659 | 0.01431287958 | 0.01708382931 | -0.0001949166613 | 0.001030215288 | 3.797834716e-06
neck_yaw | 0.4529434912 | -1.726831099e-07 | -0.0007048891988 | 0.06096058434 | 0.0003043983388 | 0.0002377448679 | 0.0002308320268 | 1.872708193e-09 | 3.236493455e-08 | 8.806948048e-06
neck_pitch | 0.610735078 | -0.05799548598 | -0.0009078086585 | 0.08185788015 | 0.00129098142 | 0.001388125293 | 0.0008716258403 | -4.547012227e-05 | 0.0005566316244 | 7.964983467e-05
neck_mid_pitch | 0.5145364405 | 0.0523937538 | 0.002063425479 | 0.06752041622 | 0.001135449873 | 0.001230554489 | 0.0008790069979 | 6.750631292e-05 | -0.0005196656194 | 8.848428022e-05
head_pitch | 0.05813070923 | 0.02054868297 | 0.005570681651 | -0.02142473107 | 2.81389835e-05 | 4.068213245e-05 | 2.937305448e-05 | 5.167956792e-06 | 8.725728094e-06 | -2.326730096e-06
head_roll | 0.6816873618 | 0.06045127576 | -0.0002698689945 | 0.009425564564 | 0.0004582916165 | 0.0007901783175 | 0.0007922064327 | -2.433958632e-06 | 0.0001296340306 | 3.323396524e-06
beak_hinge | 0.1244418433 | 0.02210534974 | 0.00217838604 | -0.01582878184 | 5.981546379e-05 | 0.0001014437819 | 0.0001160317762 | 6.67054864e-06 | 3.187950296e-05 | -3.102445199e-06
right_hip_yaw | 0.4679029511 | -0.02222674675 | 8.851795824e-10 | -0.04114163682 | 0.0005134200786 | 0.0007198312073 | 0.0003703139631 | -8.413091554e-12 | -0.0002065414875 | -4.797798841e-10
right_hip_roll | 0.4793867925 | 0.05958013713 | -0.01038821479 | -0.01159764983 | 0.0002604957102 | 0.0002787778305 | 0.000358025978 | -3.249242209e-07 | 2.35189591e-05 | -5.983451374e-06
right_hip_pitch | 0.5993243195 | -0.0516592578 | 0.001718937648 | -0.09139366996 | 0.001399502299 | 0.001415588206 | 0.0007685572504 | 3.751710561e-05 | -0.0005257418808 | 6.638261684e-05
right_knee_pitch | 0.6123304184 | 0.03970846911 | 0.0007221527825 | -0.07007417028 | 0.001236804185 | 0.00107399617 | 0.0007863182676 | -6.568197705e-05 | 0.0003768975866 | 0.0001159087277
right_ankle_pitch | 0.4346741956 | 0.04590239803 | -0.005313866192 | -0.01506883106 | 0.0004914091039 | 0.0005055478161 | 0.0005857760746 | -4.867839763e-05 | 0.0001254846894 | 1.95027352e-05
right_ankle_roll | 0.292980652 | -0.01592988758 | -7.502205121e-08 | -0.02223754673 | 0.0001849228672 | 0.000794205995 | 0.00087533372 | 2.453468801e-08 | -4.057991887e-05 | 2.016839751e-11
left_hip_yaw | 0.4679029511 | -0.02222674675 | 8.85179624e-10 | -0.04114163682 | 0.0005134200786 | 0.0007198312073 | 0.0003703139631 | -8.413091373e-12 | -0.0002065414875 | -4.797798862e-10
left_hip_roll | 0.4793867846 | 0.05958013757 | 0.01038830433 | -0.01159774662 | 0.0002604943681 | 0.0002787783321 | 0.000358024123 | 3.260651245e-07 | 2.351772725e-05 | 5.969887996e-06
left_hip_pitch | 0.5993241244 | -0.05165648481 | -0.001718937785 | -0.09139215608 | 0.001399670858 | 0.001415582277 | 0.0007683822572 | -3.752157673e-05 | -0.0005252354022 | -6.638520409e-05
left_knee_pitch | 0.6123304566 | 0.03970826758 | -0.0007221520383 | -0.07007372114 | 0.001236821855 | 0.001074032926 | 0.0007863374873 | 6.568612471e-05 | 0.0003770177372 | -0.0001159115399
left_ankle_pitch | 0.434674192 | 0.04590239774 | 0.005313881999 | -0.01506899776 | 0.0004914096559 | 0.0005055398692 | 0.0005857845677 | 4.867827583e-05 | 0.0001254864085 | -1.952567194e-05
left_ankle_roll | 0.292980652 | -0.01592988758 | -7.502205218e-08 | -0.02223754673 | 0.0001849228672 | 0.000794205995 | 0.00087533372 | 2.45346877e-08 | -4.057991887e-05 | 2.016833772e-11

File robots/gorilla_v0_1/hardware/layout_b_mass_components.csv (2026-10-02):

body | name | mass_kg | shape | position_world_m | basis | uncertainty_fraction
pelvis | pelvis_frame | 12 | box | [0, 0, 1.5800000000000003] | estimated component/frame allocation; not solid material volume | 0.3
pelvis | battery_32s_60ah | 58 | box | [-0.045, 0, 1.6250000000000002] | estimated component/frame allocation; not solid material volume | 0.3
pelvis | unmodelled_mounts_reserve | 8 | box | [0, 0, 1.6] | estimated component/frame allocation; not solid material volume | 0.3
pelvis | saffron_front_pelvis | 2.4201045857493932 | surface_skin | [0.36282962582697065, -2.141011413795587e-06, 1.574866526359169] | independent thin surface approximation; no strength or fabrication proof | 0.3
pelvis | rear_saffron_pelvis_band | 2.4161938434436165 | surface_skin | [-0.20373250261862166, -5.665914207943904e-07, 1.62505289510808] | independent thin surface approximation; no strength or fabrication proof | 0.3
pelvis | rear_ivory_sacral_guard | 1.7525886467181262 | surface_skin | [-0.25037230084010376, -9.249457639730891e-08, 1.5109837267849184] | independent thin surface approximation; no strength or fabrication proof | 0.3
waist_yaw_link | waist_yaw_gearbox | 7 | cylinder | [0, 0, 1.74] | complete-module cylinder proxy; all drive mass lumped to child; internal allocation unresolved | 0.2
waist_yaw_link | waist_yaw_motor | 3 | cylinder | [0, 0, 1.74] | complete-module cylinder proxy; all drive mass lumped to child; internal allocation unresolved | 0.2
waist_yaw_link | waist_yaw_output_bearing | 1.5 | cylinder | [0, 0, 1.74] | complete-module cylinder proxy; all drive mass lumped to child; internal allocation unresolved | 0.2
waist_yaw_link | waist_yaw_housing_mount | 1.2 | cylinder | [0, 0, 1.74] | complete-module cylinder proxy; all drive mass lumped to child; internal allocation unresolved | 0.2
waist_yaw_link | waist_yaw_driver_encoder | 0.6 | cylinder | [0, 0, 1.74] | complete-module cylinder proxy; all drive mass lumped to child; internal allocation unresolved | 0.2
waist_yaw_link | waist_yaw_brake | 0.9 | cylinder | [0, 0, 1.74] | complete-module cylinder proxy; all drive mass lumped to child; internal allocation unresolved | 0.2
waist_pitch_link | waist_pitch_gearbox | 20.9 | cylinder | [0, 0, 1.74] | complete-module cylinder proxy; all drive mass lumped to child; internal allocation unresolved | 0.2
waist_pitch_link | waist_pitch_motor | 6 | cylinder | [0, 0, 1.74] | complete-module cylinder proxy; all drive mass lumped to child; internal allocation unresolved | 0.2
waist_pitch_link | waist_pitch_output_bearing | 2 | cylinder | [0, 0, 1.74] | complete-module cylinder proxy; all drive mass lumped to child; internal allocation unresolved | 0.2
waist_pitch_link | waist_pitch_housing_mount | 2 | cylinder | [0, 0, 1.74] | complete-module cylinder proxy; all drive mass lumped to child; internal allocation unresolved | 0.2
waist_pitch_link | waist_pitch_driver_encoder | 1 | cylinder | [0, 0, 1.74] | complete-module cylinder proxy; all drive mass lumped to child; internal allocation unresolved | 0.2
waist_pitch_link | waist_pitch_brake | 2 | cylinder | [0, 0, 1.74] | complete-module cylinder proxy; all drive mass lumped to child; internal allocation unresolved | 0.2
torso | torso_frame | 18 | box | [-0.05, 0, 2.2299999999999995] | estimated component/frame allocation; not solid material volume | 0.3
torso | power_protection_distribution | 6 | box | [-0.12, -0.25, 2.05] | estimated component/frame allocation; not solid material volume | 0.3
torso | logic_compute_sensors | 5 | box | [0.045, 0, 2.49] | estimated component/frame allocation; not solid material volume | 0.3
torso | cooling_system_reserve | 10 | box | [0.23, 0, 2.21] | estimated component/frame allocation; not solid material volume | 0.3
torso | cables_connectors_reserve | 8 | box | [0, 0, 2.11] | estimated component/frame allocation; not solid material volume | 0.3
torso | waist_roll_gearbox | 20.9 | cylinder | [0, 0, 1.74] | complete-module cylinder proxy; all drive mass lumped to child; internal allocation unresolved | 0.2
torso | waist_roll_motor | 6 | cylinder | [0, 0, 1.74] | complete-module cylinder proxy; all drive mass lumped to child; internal allocation unresolved | 0.2
torso | waist_roll_output_bearing | 2 | cylinder | [0, 0, 1.74] | complete-module cylinder proxy; all drive mass lumped to child; internal allocation unresolved | 0.2
torso | waist_roll_housing_mount | 2 | cylinder | [0, 0, 1.74] | complete-module cylinder proxy; all drive mass lumped to child; internal allocation unresolved | 0.2
torso | waist_roll_driver_encoder | 1 | cylinder | [0, 0, 1.74] | complete-module cylinder proxy; all drive mass lumped to child; internal allocation unresolved | 0.2
torso | waist_roll_brake | 2 | cylinder | [0, 0, 1.74] | complete-module cylinder proxy; all drive mass lumped to child; internal allocation unresolved | 0.2
torso | ivory_chest_wedge | 11.137785445798725 | surface_skin | [0.2681263268558513, 6.399604115734155e-05, 2.3485256276079274] | independent thin surface approximation; no strength or fabrication proof | 0.3
torso | ivory_back_carapace | 14.087539386195658 | surface_skin | [-0.2948028012560151, 9.36693836855688e-06, 2.2868747416276256] | independent thin surface approximation; no strength or fabrication proof | 0.3
torso | left_blue_torso_side | 5.871536899186067 | surface_skin | [0.17355860811655868, 0.33568618392450517, 2.2431758487724176] | independent thin surface approximation; no strength or fabrication proof | 0.3
torso | left_blue_rear_side_transition | 3.7641300540003972 | surface_skin | [-0.20800407064362542, 0.3674113211238, 2.21780074329192] | independent thin surface approximation; no strength or fabrication proof | 0.3
torso | left_upper_blue_shoulder_bridge | 3.003471630515508 | surface_skin | [-0.08060088736580392, 0.5422533258875003, 2.4814108920491167] | independent thin surface approximation; no strength or fabrication proof | 0.3
torso | left_radiator_gold_frame | 1.0527570000000004 | surface_skin | [0.486, 0.3349999999999999, 2.2349999999999994] | independent thin surface approximation; no strength or fabrication proof | 0.3
torso | right_blue_torso_side | 5.871566982652204 | surface_skin | [0.17354965627390773, -0.3356811799990484, 2.2431737404953975] | independent thin surface approximation; no strength or fabrication proof | 0.3
torso | right_blue_rear_side_transition | 3.764135012402313 | surface_skin | [-0.2080116579901635, -0.36741018021613614, 2.21779778756338] | independent thin surface approximation; no strength or fabrication proof | 0.3
torso | right_upper_blue_shoulder_bridge | 3.003471630321483 | surface_skin | [-0.08060088735955782, -0.5422533258641475, 2.4814108920630917] | independent thin surface approximation; no strength or fabrication proof | 0.3
torso | right_radiator_gold_frame | 1.0527570000000004 | surface_skin | [0.486, -0.3349999999999999, 2.2349999999999994] | independent thin surface approximation; no strength or fabrication proof | 0.3
torso | central_amber_light_rim | 0.37827 | surface_skin | [0.5049999999999999, 0.0, 2.17] | independent thin surface approximation; no strength or fabrication proof | 0.3
torso | blue_back_service_panel | 2.1210979426370025 | surface_skin | [-0.4695500488212338, 1.0237460373683691e-08, 2.3487940557233795] | independent thin surface approximation; no strength or fabrication proof | 0.3
left_shoulder_pitch_link | left_shoulder_pitch_gearbox | 7 | cylinder | [-0.05, 0.62, 2.29] | complete-module cylinder proxy; all drive mass lumped to child; internal allocation unresolved | 0.2
left_shoulder_pitch_link | left_shoulder_pitch_motor | 3 | cylinder | [-0.05, 0.62, 2.29] | complete-module cylinder proxy; all drive mass lumped to child; internal allocation unresolved | 0.2
left_shoulder_pitch_link | left_shoulder_pitch_output_bearing | 1.5 | cylinder | [-0.05, 0.62, 2.29] | complete-module cylinder proxy; all drive mass lumped to child; internal allocation unresolved | 0.2
left_shoulder_pitch_link | left_shoulder_pitch_housing_mount | 1.2 | cylinder | [-0.05, 0.62, 2.29] | complete-module cylinder proxy; all drive mass lumped to child; internal allocation unresolved | 0.2
left_shoulder_pitch_link | left_shoulder_pitch_driver_encoder | 0.6 | cylinder | [-0.05, 0.62, 2.29] | complete-module cylinder proxy; all drive mass lumped to child; internal allocation unresolved | 0.2
left_shoulder_pitch_link | left_shoulder_pitch_brake | 0.9 | cylinder | [-0.05, 0.62, 2.29] | complete-module cylinder proxy; all drive mass lumped to child; internal allocation unresolved | 0.2
left_shoulder_roll_link | left_shoulder_roll_gearbox | 7 | cylinder | [-0.05, 0.62, 2.29] | complete-module cylinder proxy; all drive mass lumped to child; internal allocation unresolved | 0.2
left_shoulder_roll_link | left_shoulder_roll_motor | 3 | cylinder | [-0.05, 0.62, 2.29] | complete-module cylinder proxy; all drive mass lumped to child; internal allocation unresolved | 0.2
left_shoulder_roll_link | left_shoulder_roll_output_bearing | 1.5 | cylinder | [-0.05, 0.62, 2.29] | complete-module cylinder proxy; all drive mass lumped to child; internal allocation unresolved | 0.2
left_shoulder_roll_link | left_shoulder_roll_housing_mount | 1.2 | cylinder | [-0.05, 0.62, 2.29] | complete-module cylinder proxy; all drive mass lumped to child; internal allocation unresolved | 0.2
left_shoulder_roll_link | left_shoulder_roll_driver_encoder | 0.6 | cylinder | [-0.05, 0.62, 2.29] | complete-module cylinder proxy; all drive mass lumped to child; internal allocation unresolved | 0.2
left_shoulder_roll_link | left_shoulder_roll_brake | 0.9 | cylinder | [-0.05, 0.62, 2.29] | complete-module cylinder proxy; all drive mass lumped to child; internal allocation unresolved | 0.2
left_upper_arm | left_upper_arm_frame | 3 | box | [-0.030000000000000002, 0.745, 1.99] | estimated component/frame allocation; not solid material volume | 0.3
left_upper_arm | left_shoulder_yaw_gearbox | 3.2 | cylinder | [-0.05, 0.62, 2.29] | complete-module cylinder proxy; all drive mass lumped to child; internal allocation unresolved | 0.2
left_upper_arm | left_shoulder_yaw_motor | 1.3 | cylinder | [-0.05, 0.62, 2.29] | complete-module cylinder proxy; all drive mass lumped to child; internal allocation unresolved | 0.2
left_upper_arm | left_shoulder_yaw_output_bearing | 0.5 | cylinder | [-0.05, 0.62, 2.29] | complete-module cylinder proxy; all drive mass lumped to child; internal allocation unresolved | 0.2
left_upper_arm | left_shoulder_yaw_housing_mount | 0.5 | cylinder | [-0.05, 0.62, 2.29] | complete-module cylinder proxy; all drive mass lumped to child; internal allocation unresolved | 0.2
left_upper_arm | left_shoulder_yaw_driver_encoder | 0.3 | cylinder | [-0.05, 0.62, 2.29] | complete-module cylinder proxy; all drive mass lumped to child; internal allocation unresolved | 0.2
left_upper_arm | left_shoulder_yaw_brake | 0.3 | cylinder | [-0.05, 0.62, 2.29] | complete-module cylinder proxy; all drive mass lumped to child; internal allocation unresolved | 0.2
left_upper_arm | left_ivory_upper_arm | 3.6180014503779834 | surface_skin | [-0.015440160367460291, 0.6891196788925773, 2.074001004631103] | independent thin surface approximation; no strength or fabrication proof | 0.3
left_upper_arm | left_blue_outer_deltoid | 3.0393639375300916 | surface_skin | [-0.07950097954138986, 0.7272334754639745, 2.2816842303526035] | independent thin surface approximation; no strength or fabrication proof | 0.3
left_forearm | left_forearm_frame | 3 | box | [0.04, 0.8400000000000001, 1.48] | estimated component/frame allocation; not solid material volume | 0.3
left_forearm | left_elbow_pitch_gearbox | 7 | cylinder | [0.03, 0.78, 1.79] | complete-module cylinder proxy; all drive mass lumped to child; internal allocation unresolved | 0.2
left_forearm | left_elbow_pitch_motor | 3 | cylinder | [0.03, 0.78, 1.79] | complete-module cylinder proxy; all drive mass lumped to child; internal allocation unresolved | 0.2
left_forearm | left_elbow_pitch_output_bearing | 1.5 | cylinder | [0.03, 0.78, 1.79] | complete-module cylinder proxy; all drive mass lumped to child; internal allocation unresolved | 0.2
left_forearm | left_elbow_pitch_housing_mount | 1.2 | cylinder | [0.03, 0.78, 1.79] | complete-module cylinder proxy; all drive mass lumped to child; internal allocation unresolved | 0.2
left_forearm | left_elbow_pitch_driver_encoder | 0.6 | cylinder | [0.03, 0.78, 1.79] | complete-module cylinder proxy; all drive mass lumped to child; internal allocation unresolved | 0.2
left_forearm | left_elbow_pitch_brake | 0.9 | cylinder | [0.03, 0.78, 1.79] | complete-module cylinder proxy; all drive mass lumped to child; internal allocation unresolved | 0.2
left_forearm | left_blue_forearm | 5.048619975562734 | surface_skin | [0.037202632921093784, 0.7848017552604988, 1.501894691335668] | independent thin surface approximation; no strength or fabrication proof | 0.3
left_wrist_yaw_link | left_wrist_yaw_gearbox | 3.2 | cylinder | [0.045, 0.79, 1.19] | complete-module cylinder proxy; all drive mass lumped to child; internal allocation unresolved | 0.2
left_wrist_yaw_link | left_wrist_yaw_motor | 1.3 | cylinder | [0.045, 0.79, 1.19] | complete-module cylinder proxy; all drive mass lumped to child; internal allocation unresolved | 0.2
left_wrist_yaw_link | left_wrist_yaw_output_bearing | 0.5 | cylinder | [0.045, 0.79, 1.19] | complete-module cylinder proxy; all drive mass lumped to child; internal allocation unresolved | 0.2
left_wrist_yaw_link | left_wrist_yaw_housing_mount | 0.5 | cylinder | [0.045, 0.79, 1.19] | complete-module cylinder proxy; all drive mass lumped to child; internal allocation unresolved | 0.2
left_wrist_yaw_link | left_wrist_yaw_driver_encoder | 0.3 | cylinder | [0.045, 0.79, 1.19] | complete-module cylinder proxy; all drive mass lumped to child; internal allocation unresolved | 0.2
left_wrist_yaw_link | left_wrist_yaw_brake | 0.3 | cylinder | [0.045, 0.79, 1.19] | complete-module cylinder proxy; all drive mass lumped to child; internal allocation unresolved | 0.2
left_wrist_pitch_link | left_wrist_pitch_gearbox | 3.2 | cylinder | [0.045, 0.79, 1.19] | complete-module cylinder proxy; all drive mass lumped to child; internal allocation unresolved | 0.2
left_wrist_pitch_link | left_wrist_pitch_motor | 1.3 | cylinder | [0.045, 0.79, 1.19] | complete-module cylinder proxy; all drive mass lumped to child; internal allocation unresolved | 0.2
left_wrist_pitch_link | left_wrist_pitch_output_bearing | 0.5 | cylinder | [0.045, 0.79, 1.19] | complete-module cylinder proxy; all drive mass lumped to child; internal allocation unresolved | 0.2
left_wrist_pitch_link | left_wrist_pitch_housing_mount | 0.5 | cylinder | [0.045, 0.79, 1.19] | complete-module cylinder proxy; all drive mass lumped to child; internal allocation unresolved | 0.2
left_wrist_pitch_link | left_wrist_pitch_driver_encoder | 0.3 | cylinder | [0.045, 0.79, 1.19] | complete-module cylinder proxy; all drive mass lumped to child; internal allocation unresolved | 0.2
left_wrist_pitch_link | left_wrist_pitch_brake | 0.3 | cylinder | [0.045, 0.79, 1.19] | complete-module cylinder proxy; all drive mass lumped to child; internal allocation unresolved | 0.2
left_palm | left_palm_frame | 1.5 | box | [0.08, 0.79, 1.08] | estimated component/frame allocation; not solid material volume | 0.3
left_palm | left_wrist_roll_gearbox | 3.2 | cylinder | [0.045, 0.79, 1.19] | complete-module cylinder proxy; all drive mass lumped to child; internal allocation unresolved | 0.2
left_palm | left_wrist_roll_motor | 1.3 | cylinder | [0.045, 0.79, 1.19] | complete-module cylinder proxy; all drive mass lumped to child; internal allocation unresolved | 0.2
left_palm | left_wrist_roll_output_bearing | 0.5 | cylinder | [0.045, 0.79, 1.19] | complete-module cylinder proxy; all drive mass lumped to child; internal allocation unresolved | 0.2
left_palm | left_wrist_roll_housing_mount | 0.5 | cylinder | [0.045, 0.79, 1.19] | complete-module cylinder proxy; all drive mass lumped to child; internal allocation unresolved | 0.2
left_palm | left_wrist_roll_driver_encoder | 0.3 | cylinder | [0.045, 0.79, 1.19] | complete-module cylinder proxy; all drive mass lumped to child; internal allocation unresolved | 0.2
left_palm | left_wrist_roll_brake | 0.3 | cylinder | [0.045, 0.79, 1.19] | complete-module cylinder proxy; all drive mass lumped to child; internal allocation unresolved | 0.2
left_palm | left_ivory_palm | 1.7604513755900904 | surface_skin | [0.08000021856344579, 0.8132168516794689, 1.0673038845001037] | independent thin surface approximation; no strength or fabrication proof | 0.3
left_hip_yaw_link | left_hip_yaw_gearbox | 7 | cylinder | [-0.1, 0.38, 1.63] | complete-module cylinder proxy; all drive mass lumped to child; internal allocation unresolved | 0.2
left_hip_yaw_link | left_hip_yaw_motor | 3 | cylinder | [-0.1, 0.38, 1.63] | complete-module cylinder proxy; all drive mass lumped to child; internal allocation unresolved | 0.2
left_hip_yaw_link | left_hip_yaw_output_bearing | 1.5 | cylinder | [-0.1, 0.38, 1.63] | complete-module cylinder proxy; all drive mass lumped to child; internal allocation unresolved | 0.2
left_hip_yaw_link | left_hip_yaw_housing_mount | 1.2 | cylinder | [-0.1, 0.38, 1.63] | complete-module cylinder proxy; all drive mass lumped to child; internal allocation unresolved | 0.2
left_hip_yaw_link | left_hip_yaw_driver_encoder | 0.6 | cylinder | [-0.1, 0.38, 1.63] | complete-module cylinder proxy; all drive mass lumped to child; internal allocation unresolved | 0.2
left_hip_yaw_link | left_hip_yaw_brake | 0.9 | cylinder | [-0.1, 0.38, 1.63] | complete-module cylinder proxy; all drive mass lumped to child; internal allocation unresolved | 0.2
left_hip_roll_link | left_hip_roll_gearbox | 20.9 | cylinder | [-0.1, 0.38, 1.63] | complete-module cylinder proxy; all drive mass lumped to child; internal allocation unresolved | 0.2
left_hip_roll_link | left_hip_roll_motor | 6 | cylinder | [-0.1, 0.38, 1.63] | complete-module cylinder proxy; all drive mass lumped to child; internal allocation unresolved | 0.2
left_hip_roll_link | left_hip_roll_output_bearing | 2 | cylinder | [-0.1, 0.38, 1.63] | complete-module cylinder proxy; all drive mass lumped to child; internal allocation unresolved | 0.2
left_hip_roll_link | left_hip_roll_housing_mount | 2 | cylinder | [-0.1, 0.38, 1.63] | complete-module cylinder proxy; all drive mass lumped to child; internal allocation unresolved | 0.2
left_hip_roll_link | left_hip_roll_driver_encoder | 1 | cylinder | [-0.1, 0.38, 1.63] | complete-module cylinder proxy; all drive mass lumped to child; internal allocation unresolved | 0.2
left_hip_roll_link | left_hip_roll_brake | 2 | cylinder | [-0.1, 0.38, 1.63] | complete-module cylinder proxy; all drive mass lumped to child; internal allocation unresolved | 0.2
left_thigh | left_thigh_frame | 6 | box | [-0.010000000000000009, 0.39, 1.3699999999999999] | estimated component/frame allocation; not solid material volume | 0.3
left_thigh | left_hip_pitch_gearbox | 20.9 | cylinder | [-0.1, 0.38, 1.63] | complete-module cylinder proxy; all drive mass lumped to child; internal allocation unresolved | 0.2
left_thigh | left_hip_pitch_motor | 6 | cylinder | [-0.1, 0.38, 1.63] | complete-module cylinder proxy; all drive mass lumped to child; internal allocation unresolved | 0.2
left_thigh | left_hip_pitch_output_bearing | 2 | cylinder | [-0.1, 0.38, 1.63] | complete-module cylinder proxy; all drive mass lumped to child; internal allocation unresolved | 0.2
left_thigh | left_hip_pitch_housing_mount | 2 | cylinder | [-0.1, 0.38, 1.63] | complete-module cylinder proxy; all drive mass lumped to child; internal allocation unresolved | 0.2
left_thigh | left_hip_pitch_driver_encoder | 1 | cylinder | [-0.1, 0.38, 1.63] | complete-module cylinder proxy; all drive mass lumped to child; internal allocation unresolved | 0.2
left_thigh | left_hip_pitch_brake | 2 | cylinder | [-0.1, 0.38, 1.63] | complete-module cylinder proxy; all drive mass lumped to child; internal allocation unresolved | 0.2
left_thigh | left_ivory_hip_transition_cuff | 0.7196612196546807 | surface_skin | [0.0214652131082375, 0.35487034654366467, 1.665162281910888] | independent thin surface approximation; no strength or fabrication proof | 0.3
left_thigh | left_blue_thigh | 6.62319513823053 | surface_skin | [0.11139284171478372, 0.40443638176030977, 1.3208536002779159] | independent thin surface approximation; no strength or fabrication proof | 0.3
left_thigh | left_orange_knee_guard | 2.1297854570600716 | surface_skin | [0.39044056740628447, 0.41443879918991394, 1.1545470249532135] | independent thin surface approximation; no strength or fabrication proof | 0.3
left_middle_shank | left_middle_shank_frame | 5 | box | [0.09, 0.43, 0.75] | estimated component/frame allocation; not solid material volume | 0.3
left_middle_shank | left_knee_pitch_gearbox | 20.9 | cylinder | [0.24, 0.43, 0.965] | complete-module cylinder proxy; all drive mass lumped to child; internal allocation unresolved | 0.2
left_middle_shank | left_knee_pitch_motor | 6 | cylinder | [0.24, 0.43, 0.965] | complete-module cylinder proxy; all drive mass lumped to child; internal allocation unresolved | 0.2
left_middle_shank | left_knee_pitch_output_bearing | 2 | cylinder | [0.24, 0.43, 0.965] | complete-module cylinder proxy; all drive mass lumped to child; internal allocation unresolved | 0.2
left_middle_shank | left_knee_pitch_housing_mount | 2 | cylinder | [0.24, 0.43, 0.965] | complete-module cylinder proxy; all drive mass lumped to child; internal allocation unresolved | 0.2
left_middle_shank | left_knee_pitch_driver_encoder | 1 | cylinder | [0.24, 0.43, 0.965] | complete-module cylinder proxy; all drive mass lumped to child; internal allocation unresolved | 0.2
left_middle_shank | left_knee_pitch_brake | 2 | cylinder | [0.24, 0.43, 0.965] | complete-module cylinder proxy; all drive mass lumped to child; internal allocation unresolved | 0.2
left_middle_shank | left_blue_middle_shank | 4.110436797339624 | surface_skin | [0.12179922209061646, 0.4584283005422043, 0.7692684366755986] | independent thin surface approximation; no strength or fabrication proof | 0.3
left_distal_shank | left_distal_shank_frame | 3 | box | [-0.015, 0.49, 0.42000000000000004] | estimated component/frame allocation; not solid material volume | 0.3
left_distal_shank | left_fold_pitch_gearbox | 7 | cylinder | [-0.105, 0.49, 0.535] | complete-module cylinder proxy; all drive mass lumped to child; internal allocation unresolved | 0.2
left_distal_shank | left_fold_pitch_motor | 3 | cylinder | [-0.105, 0.49, 0.535] | complete-module cylinder proxy; all drive mass lumped to child; internal allocation unresolved | 0.2
left_distal_shank | left_fold_pitch_output_bearing | 1.5 | cylinder | [-0.105, 0.49, 0.535] | complete-module cylinder proxy; all drive mass lumped to child; internal allocation unresolved | 0.2
left_distal_shank | left_fold_pitch_housing_mount | 1.2 | cylinder | [-0.105, 0.49, 0.535] | complete-module cylinder proxy; all drive mass lumped to child; internal allocation unresolved | 0.2
left_distal_shank | left_fold_pitch_driver_encoder | 0.6 | cylinder | [-0.105, 0.49, 0.535] | complete-module cylinder proxy; all drive mass lumped to child; internal allocation unresolved | 0.2
left_distal_shank | left_fold_pitch_brake | 0.9 | cylinder | [-0.105, 0.49, 0.535] | complete-module cylinder proxy; all drive mass lumped to child; internal allocation unresolved | 0.2
left_distal_shank | left_blue_distal_front_guard | 0.7994186481040706 | surface_skin | [0.04947409535772238, 0.5086341681904873, 0.3959629155295751] | independent thin surface approximation; no strength or fabrication proof | 0.3
left_ankle_pitch_link | left_ankle_pitch_gearbox | 7 | cylinder | [-0.07, 0.53, 0.27] | complete-module cylinder proxy; all drive mass lumped to child; internal allocation unresolved | 0.2
left_ankle_pitch_link | left_ankle_pitch_motor | 3 | cylinder | [-0.07, 0.53, 0.27] | complete-module cylinder proxy; all drive mass lumped to child; internal allocation unresolved | 0.2
left_ankle_pitch_link | left_ankle_pitch_output_bearing | 1.5 | cylinder | [-0.07, 0.53, 0.27] | complete-module cylinder proxy; all drive mass lumped to child; internal allocation unresolved | 0.2
left_ankle_pitch_link | left_ankle_pitch_housing_mount | 1.2 | cylinder | [-0.07, 0.53, 0.27] | complete-module cylinder proxy; all drive mass lumped to child; internal allocation unresolved | 0.2
left_ankle_pitch_link | left_ankle_pitch_driver_encoder | 0.6 | cylinder | [-0.07, 0.53, 0.27] | complete-module cylinder proxy; all drive mass lumped to child; internal allocation unresolved | 0.2
left_ankle_pitch_link | left_ankle_pitch_brake | 0.9 | cylinder | [-0.07, 0.53, 0.27] | complete-module cylinder proxy; all drive mass lumped to child; internal allocation unresolved | 0.2
left_foot | left_foot_frame | 6 | box | [0.14, 0.575, 0.09] | estimated component/frame allocation; not solid material volume | 0.3
left_foot | left_ankle_roll_gearbox | 7 | cylinder | [-0.07, 0.53, 0.27] | complete-module cylinder proxy; all drive mass lumped to child; internal allocation unresolved | 0.2
left_foot | left_ankle_roll_motor | 3 | cylinder | [-0.07, 0.53, 0.27] | complete-module cylinder proxy; all drive mass lumped to child; internal allocation unresolved | 0.2
left_foot | left_ankle_roll_output_bearing | 1.5 | cylinder | [-0.07, 0.53, 0.27] | complete-module cylinder proxy; all drive mass lumped to child; internal allocation unresolved | 0.2
left_foot | left_ankle_roll_housing_mount | 1.2 | cylinder | [-0.07, 0.53, 0.27] | complete-module cylinder proxy; all drive mass lumped to child; internal allocation unresolved | 0.2
left_foot | left_ankle_roll_driver_encoder | 0.6 | cylinder | [-0.07, 0.53, 0.27] | complete-module cylinder proxy; all drive mass lumped to child; internal allocation unresolved | 0.2
left_foot | left_ankle_roll_brake | 0.9 | cylinder | [-0.07, 0.53, 0.27] | complete-module cylinder proxy; all drive mass lumped to child; internal allocation unresolved | 0.2
left_foot | left_dark_sole | 9.03306509142322 | surface_skin | [0.13999999999999999, 0.5749999999999997, 0.02513996975518512] | independent thin surface approximation; no strength or fabrication proof | 0.3
left_foot | left_ivory_foot_upper | 8.265479103423868 | surface_skin | [0.1529502001081664, 0.5749986493310275, 0.09501541943449589] | independent thin surface approximation; no strength or fabrication proof | 0.3
left_foot | left_dark_rear_heel | 2.9965585525765412 | surface_skin | [-0.16766370626965, 0.5749998011493719, 0.09937721606417711] | independent thin surface approximation; no strength or fabrication proof | 0.3
left_foot | left_ivory_ankle_inst_ep | 1.690549211867931 | surface_skin | [0.01872715577968306, 0.5750007430326022, 0.1804099242419511] | independent thin surface approximation; no strength or fabrication proof | 0.3
left_finger_1_proximal_link | left_finger_1_proximal_custom_motor_gear_bracket_driver | 0.8 | cylinder | [0.11, 0.688, 0.97] | complete-module cylinder proxy; all drive mass lumped to child; internal allocation unresolved | 0.2
left_finger_1_proximal_link | left_finger_1_proximal | 0.20427741900952953 | surface_skin | [0.11000000000000003, 0.688, 0.9253778610741147] | independent thin surface approximation; no strength or fabrication proof | 0.3
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

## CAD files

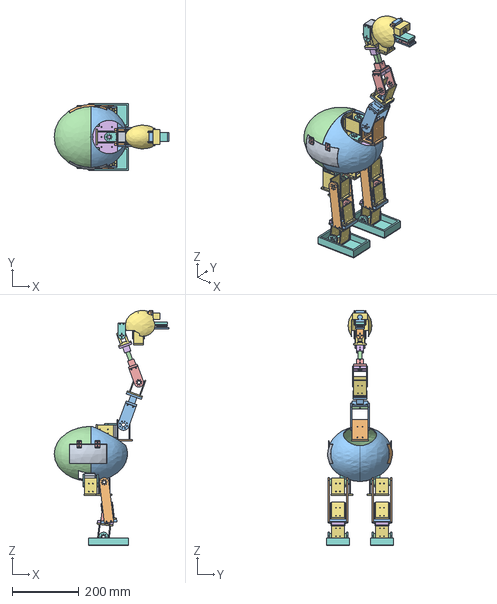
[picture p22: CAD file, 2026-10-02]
robots/Goose_V0.1/cad/exports/goose_rc1_assembly.step
344.0 x 202.0 x 705.1 mm

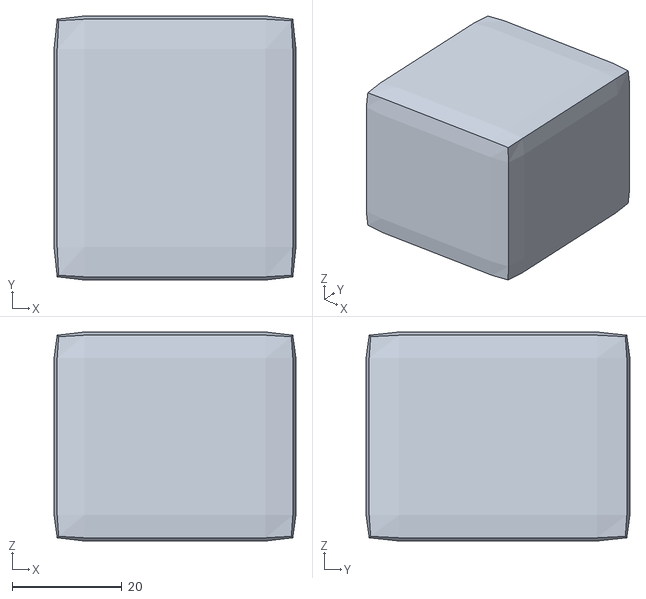
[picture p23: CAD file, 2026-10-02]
robots/Goose_V0.1/cad/source/fuller_exterior_candidate/access/quad_source/main_protection.obj
44.0 x 48.0 x 38.0

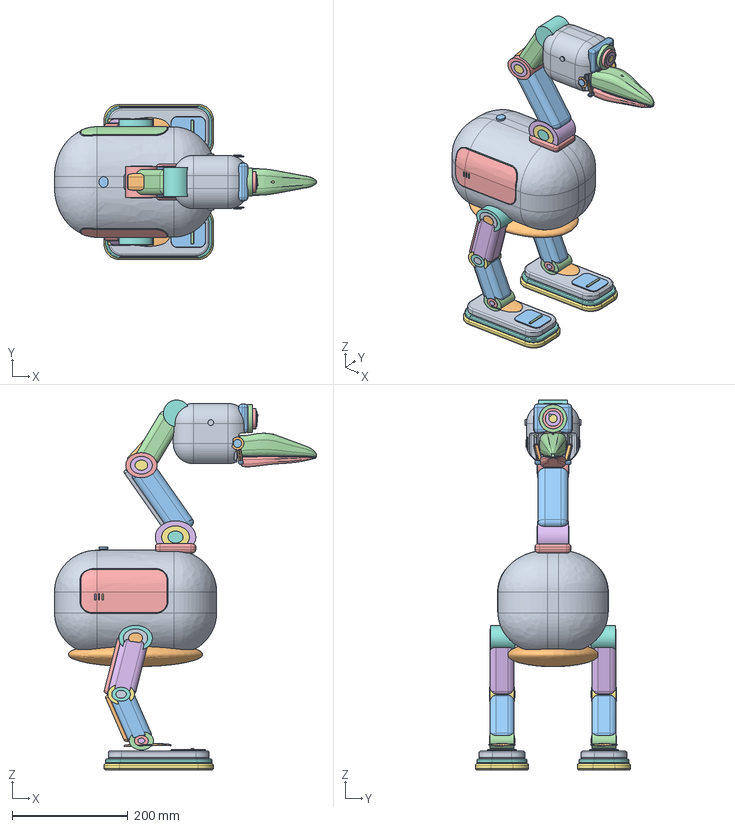
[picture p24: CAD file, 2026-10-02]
robots/Goose_V0.1/cad/exports/goose_r2_whole_proportions_v92_visual_closed_candidate.step
452.4 x 268.0 x 638.8 mm

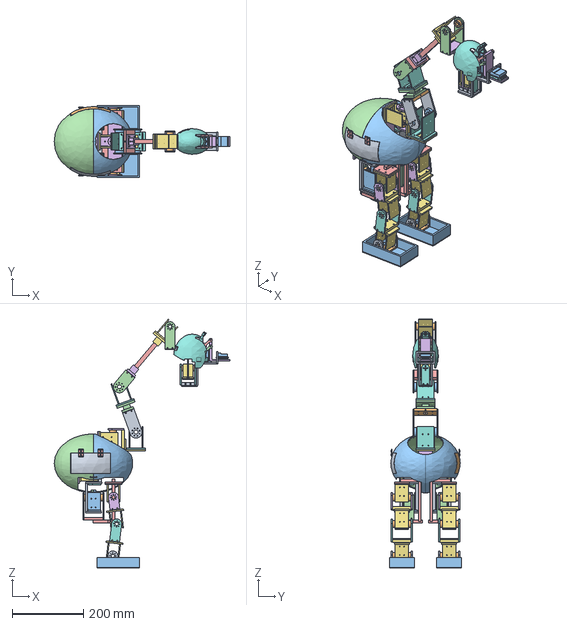
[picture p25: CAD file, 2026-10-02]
robots/Goose_V0.1/cad/exports/goose_rc2_assembly.step
491.6 x 202.0 x 696.8 mm

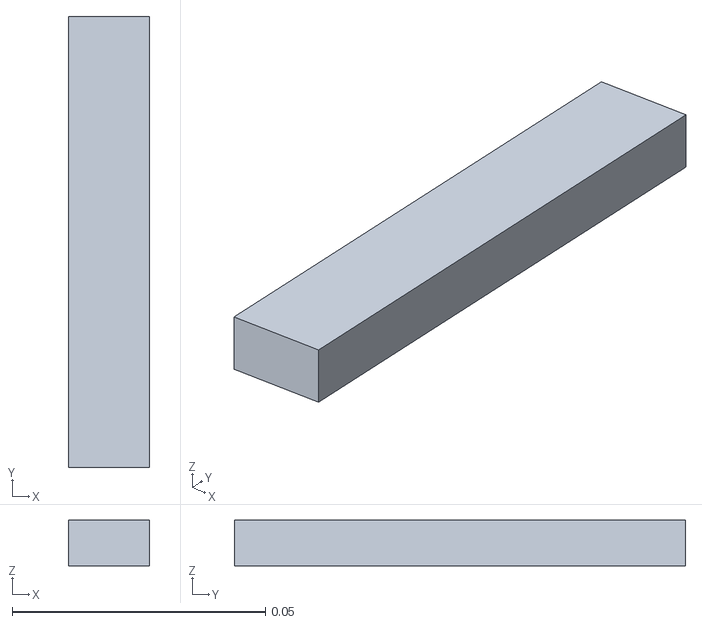
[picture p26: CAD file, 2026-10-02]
experiments/gorilla_v0_1/layout_b_initial_rejection/models/assets/right_radiator_louver_08.obj
0.016 x 0.089 x 0.009

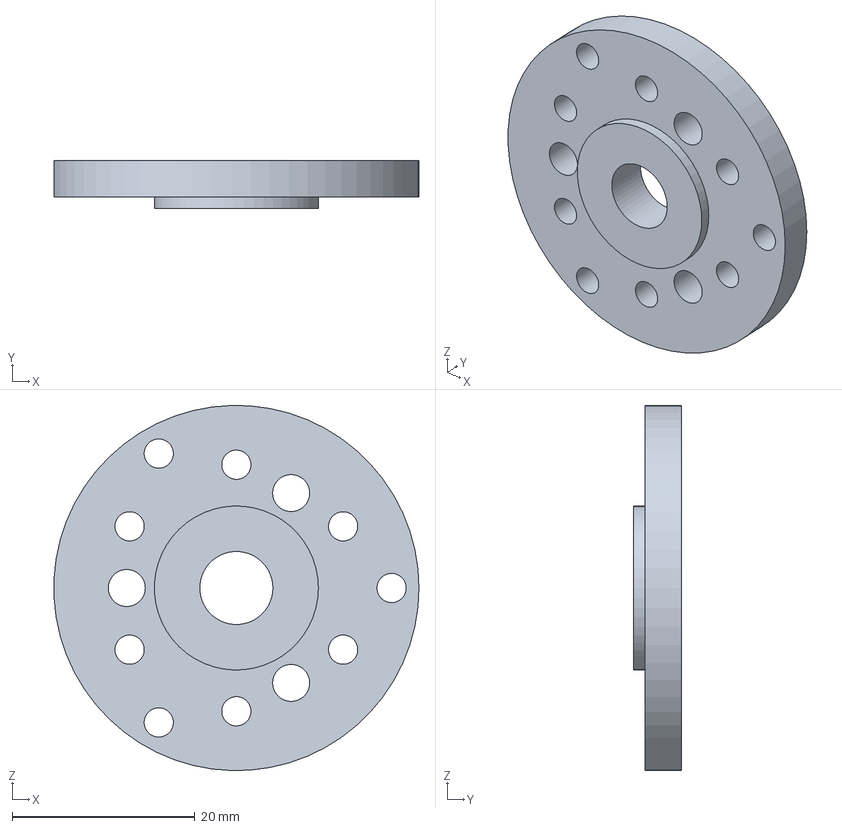
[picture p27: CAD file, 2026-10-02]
robots/Goose_V0.1/cad/exports/actuator_interfaces/ak45_36_v3_output_adapter.step
40.0 x 5.30 x 40.0 mm

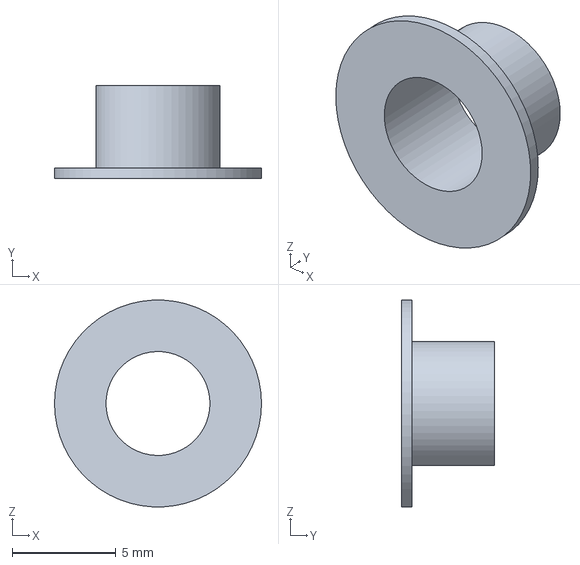
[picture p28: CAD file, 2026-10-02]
robots/Goose_V0.1/cad/exports/beak_native_linkage/beak_output_bush_candidate.step
10.0 x 4.50 x 9.99 mm

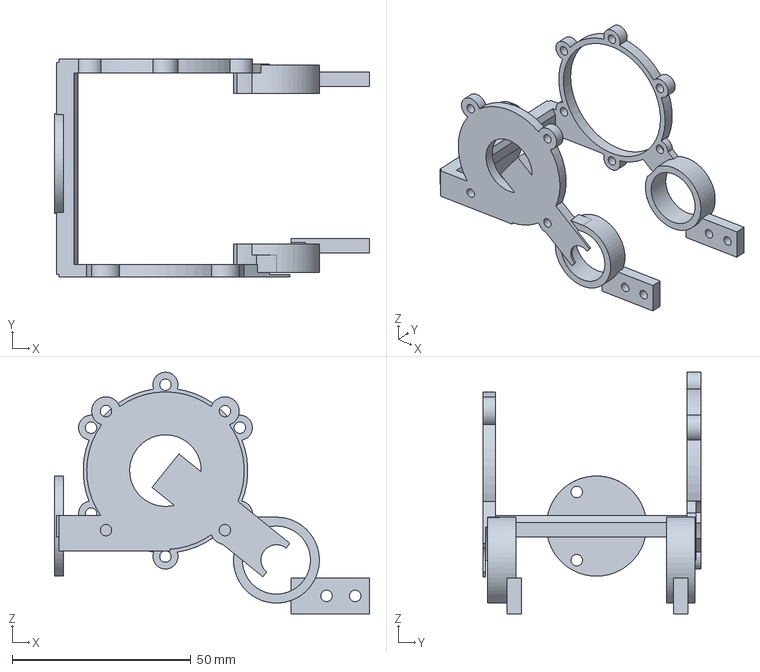
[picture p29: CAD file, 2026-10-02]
robots/Goose_V0.1/cad/exports/bill_backbones/head_frame_with_bill_mounts.step
88.0 x 61.0 x 67.5 mm

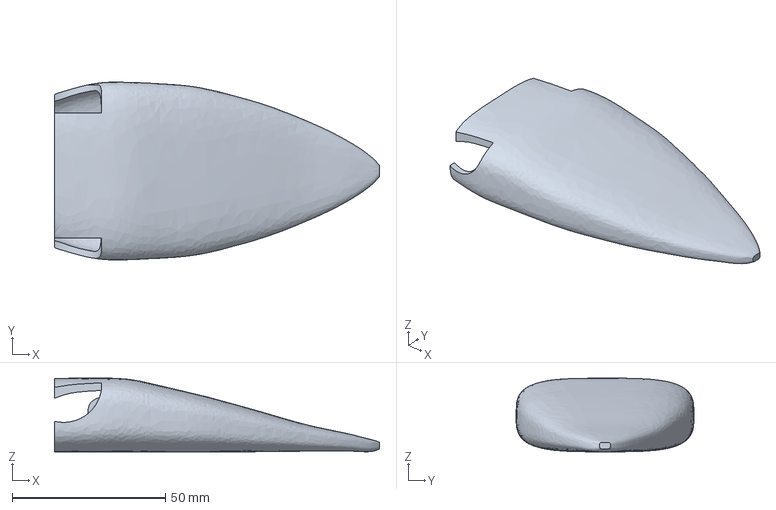
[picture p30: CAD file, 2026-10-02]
robots/Goose_V0.1/cad/exports/bill_shells/upper_bill_hollow_shell.step
106.0 x 58.0 x 24.0 mm

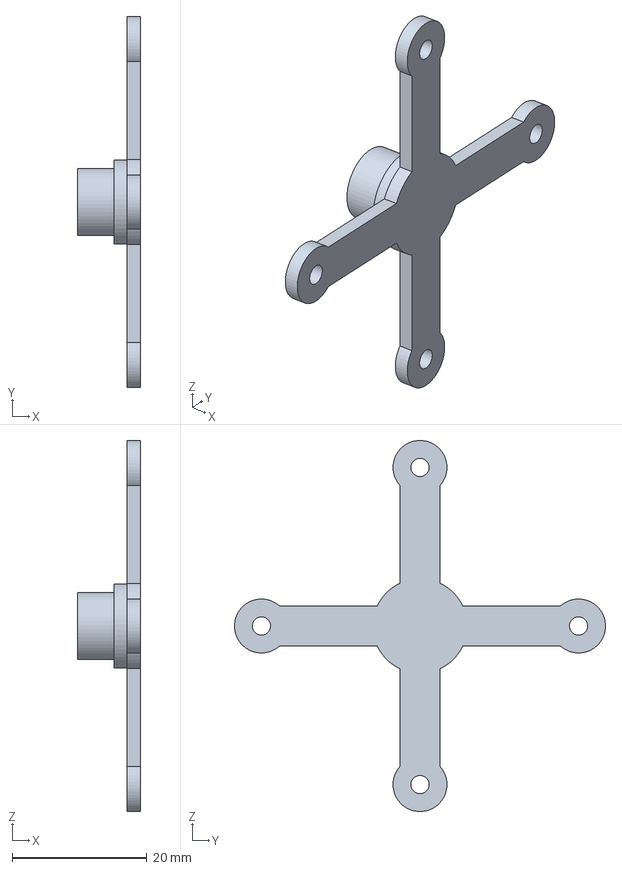
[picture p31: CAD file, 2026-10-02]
robots/Goose_V0.1/cad/exports/body_bay_ankle_assembly/right_ankle_roll_stationary_spider.step
9.30 x 55.0 x 55.0 mm

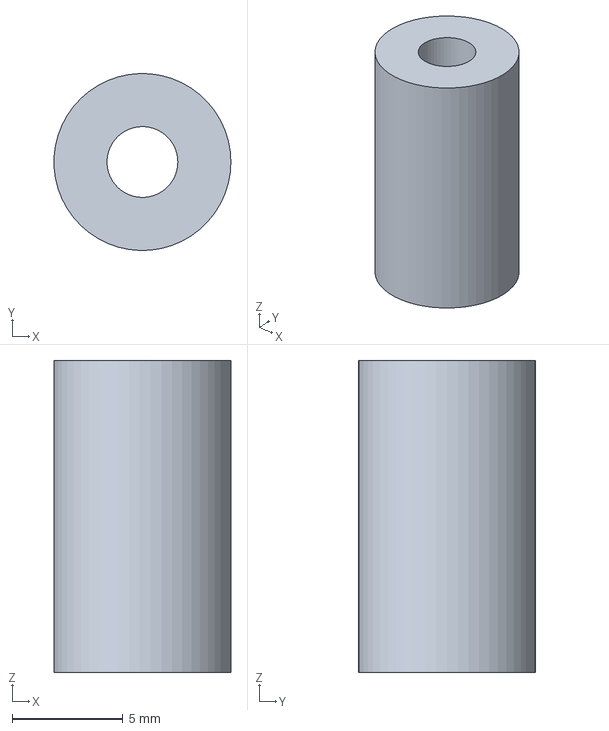
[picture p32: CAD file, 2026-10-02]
robots/Goose_V0.1/cad/exports/body_bay_frame/left_battery_frame_post_1.step
7.99 x 8.00 x 14.1 mm

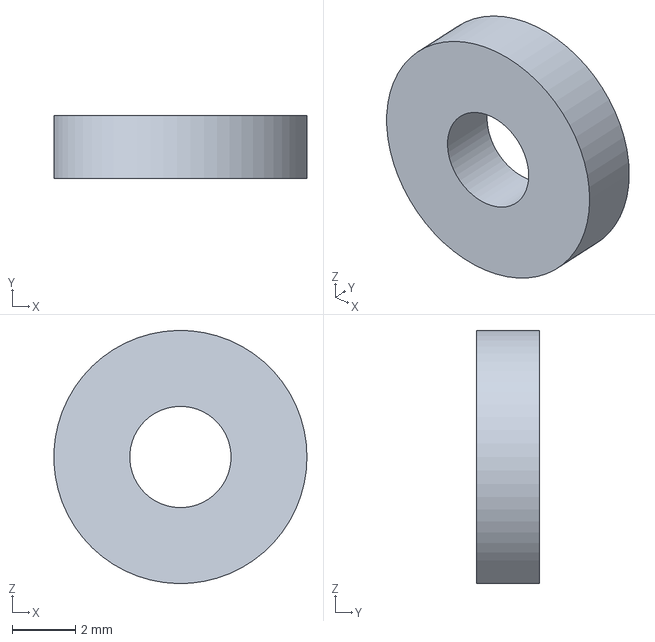
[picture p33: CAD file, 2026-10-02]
robots/Goose_V0.1/cad/exports/body_bay_pitch_forks/right_shin_distal_rear_spacer_middle_3.step
7.99 x 2.00 x 8.00 mm

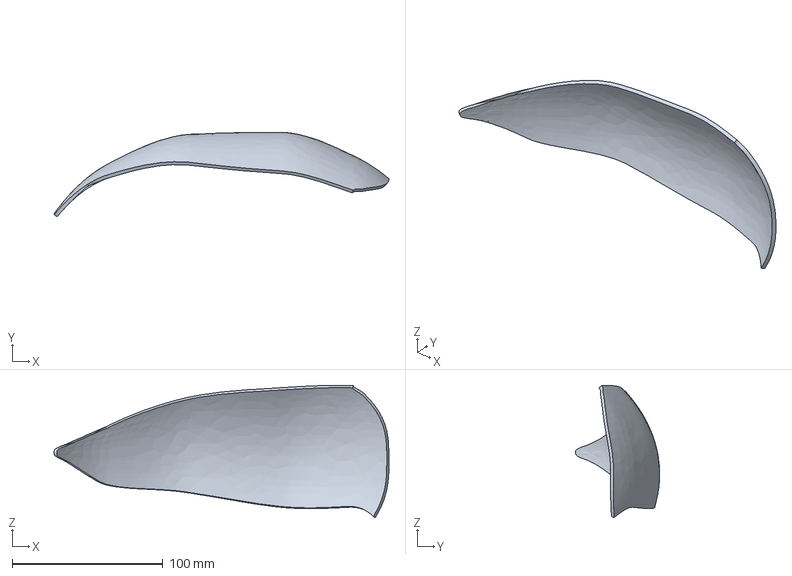
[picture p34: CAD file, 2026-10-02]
robots/Goose_V0.1/cad/exports/body_bay_skins/wing_access_cover_left.step
222.3 x 56.0 x 87.8 mm

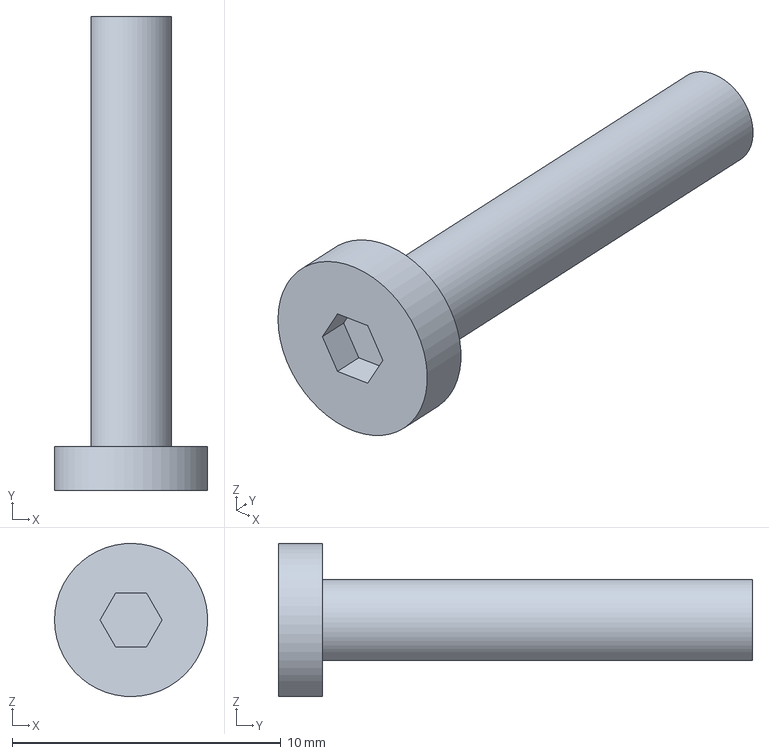
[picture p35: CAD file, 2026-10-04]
robots/Goose_V0.1/cad/exports/brake_packaging/brake_rd_0_2_m3x16.step
5.69 x 17.6 x 5.70 mm

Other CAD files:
robots/Goose_V0.1/cad/exports/goose_r2_whole_proportions_v92_visual_open_candidate.step
robots/Goose_V0.1/cad/exports/body_bay_roll_carriers/left_hip_roll_output_adapter.step
experiments/gorilla_v0_1/appearance_c_round_eleven/appearance_c.blend
experiments/gorilla_v0_1/appearance_c_round_fifteen/appearance_c.blend
experiments/gorilla_v0_1/appearance_c_round_five/appearance_c.blend
experiments/gorilla_v0_1/appearance_c_round_four/appearance_c.blend
experiments/gorilla_v0_1/appearance_c_round_fourteen/appearance_c.blend
experiments/gorilla_v0_1/appearance_c_round_nine/appearance_c.blend
experiments/gorilla_v0_1/appearance_c_round_seven/appearance_c.blend
experiments/gorilla_v0_1/appearance_c_round_ten/appearance_c.blend
experiments/gorilla_v0_1/appearance_c_round_thirteen/appearance_c.blend
experiments/gorilla_v0_1/appearance_c_round_twelve/appearance_c.blend
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

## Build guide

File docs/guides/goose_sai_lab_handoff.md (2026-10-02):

# Goose V0.1 → Sai_Lab 接入入口

当前交接使用 [460 件一体头壳训练检查点](../../robots/Goose_V0.1/design/training_checkpoint_handoff.md)：`goose_one_piece_head_training_checkpoint_si_v1`、18 主动轴、条件质量 10.430762603 kg、65 项观测和 18 项动作。`models/full/` 仍是历史 RC2，不能把默认目录当成当前机器人，也不能沿用旧策略的验收结论。

## 从主干源码开始

完整克隆后先按 [LFS 说明](large_asset_checkout.md)获取大型资产。在仓库根目录使用 Python 3.12：

```sh
uv sync --locked
uv run --no-sync python scripts/diagnostics/check_goose_training_checkpoint.py --steps 10 --output artifacts/Goose_V0.1/checkpoint_entry.json
```

检查源身份、接口、质量和短时名义物理；结果不能当作步行或硬件验收。已有交付证据允许初始训练探索，完整制造、电气、动态任务及跨引擎门槛仍未闭合。Sai_Lab 应显式读取 `models/training_checkpoint/robot.xml` 与 `configs/training_checkpoint_contract.json`，保持轴序、完整惯量、软垫、被动嘴部约束和三层时序。

需要运行小规模入口试验时，另选全新的输出目录：

```sh
uv sync --locked --extra goose-train
uv run --no-sync python scripts/training/train_goose_checkpoint.py --output artifacts/Goose_V0.1/checkpoint_trial --iterations 2 --envs 1 --horizon 4 --device cpu
```

这只示范如何消费当前模型，不是已训练成功的策略。MuJoCo 负责 CPU 物理，`--device cuda` 仅改变网络设备。其他后端按同一中立 SI 契约适配，不能借用历史 Jolt 单项记录宣布当前版本通过。

## 历史接入说明

> 第二阶段历史候选见 [第二阶段 18 轴参数交接](../../robots/Goose_V0.1/design/stage_two_parameter_handoff.md)，`--stage stage_two`；质量 8.854kg。它与当前一体头壳检查点不同版。

> 上一阶段历史基线见 [第一阶段结构与物理参数交接](../../robots/Goose_V0.1/design/stage_one_parameter_handoff.md)。本页以下保留旧 RC2 的历史接入说明；旧 16 轴模型/策略不适用于新版。

### RC2 工程候选

本页说明怎样从 Sai_Rotbots 工作区接入 Goose 的模型和训练接口。**当前只有站立和若干预设接触单项通过，尚无可交付的行走/拖拽自主策略，不能将它设为 Sai_Lab 默认机器人。** 完整门槛见[机器人放行判定](../../robots/Goose_V0.1/design/release_readiness.md)。

当前可加载资产属于 **RC2 历史工程候选**。用户指定的尖嘴 v73 外形与它不是同一具机器人：[候选一致性检查](../../robots/Goose_V0.1/evidence/r2_slim_bill_v73_model_alignment.json)检出 R2 嘴的支点距 `14 vs 18 mm`、电机 `XL330 vs XC330`、传动 `2:1 vs 1:1`，且 v73 的外形清单没有与 RC2 的模型／制造清单建立同版来源。可运行不等于适合拿去训练当前外形；这项检查是必要门槛，通过后仍须另验夹取、拖拽、步行和跨引擎行为。

## 可直接读取的资产

- 机器人 ID `Goose_V0.1` 已登记在 [catalog](../../robots/catalog.json)，源码和安装包均可通过 `sai_agent.paths.model_root('Goose_V0.1')` 找到 `models/full/robot.xml`。现行模型 SHA-256 `07d4209a5a7b9322a04b9cdb62694a69cf35c97716c262909d21f039599c4cb0`。
- [rigid_transfer.json](../../robots/Goose_V0.1/models/full/rigid_transfer.json)是后端中立 SI 交换包，含质量/完整惯量、几何、关节与被动件、点闭环、相机/任务点及 `standing`、`ground_side_grasp` 两个具名姿态。Godot 的坐标转换和质量缩放只在 [Godot 接收器](../../integrations/godot/goose_robot/goose_adapter.gd)内部。UnitySim2Sim 与 BevySim2Sim 应各自按[一致性核查清单](../../robots/Goose_V0.1/design/backend_conformance_facts.md)实现，不复制 Jolt 私有参数。
- `goose_rc2_v5` 控制契约：53 维仅传感/指令观测、10 维腿部动作、16 维有序执行关节力矩；20 ms 策略周期、5 ms 扭矩周期。动作目标为 `standing` 腿角 `+ 0.30 rad × clip(action,-1,1)`；`q-home` 只用于观测字段。训练与接收器都使用中立刚体重力前馈，腿部阻尼按真实 5 ms 更新周期复测；策略元数据必须与模型、规格、名字顺序和契约版本匹配。[v4 失稳原因和 v5 站立结果](../../robots/Goose_V0.1/design/locomotion_review.md)单独记录。

## 工作区验证入口

在此仓库根运行：

```sh
uv run pytest -q tests/test_goose_interfaces.py tests/test_goose_imu_audio.py tests/test_goose_transfer_contract.py
uv run python scripts/diagnostics/check_goose_delivery.py
uv run python scripts/evaluation/evaluate_goose_stand.py --standing-pose --shared-controller --no-double-support --output artifacts/Goose_V0.1/stand_policy_mode.json
uv run python scripts/evaluation/evaluate_goose_bridge.py --output artifacts/Goose_V0.1/godot_policy_mode
```

Godot 回放的 `--output` 每次选一个新的目录名，防止覆盖上次证据。

在将某个新外形候选交给 Sai_Lab 前，运行 `uv run python scripts/diagnostics/check_goose_candidate_alignment.py --evidence artifacts/Goose_V0.1/candidate_alignment.json`。当前 v73 对 RC2 **预期返回非零**；不能通过跳过此检查或沿用 RC2 的通过记录来放行。

RSL 训练入口是 `scripts/training/train_goose_rsl.py`，输出检查点、ONNX、元数据与精确输入快照；策略回放入口是 `scripts/evaluation/evaluate_goose_walk.py`。这些入口适合实验，但训练能跑通、ONNX 数值一致或自由站立通过都不代表游戏任务成功。[v5 原策略](../../robots/Goose_V0.1/evidence/walk_policy_200iter_v5_rc2.json)和[低探索对照策略](../../robots/Goose_V0.1/evidence/walk_policy_calm_init_v5_200_rc2.json)四项回放均失败；失败策略只在 `experiments/Goose_V0.1/` 供诊断，禁止默认装载。正式策略需通过步行、带物、拖拽和跨引擎验收，并另做用户定义的实物门槛。

安装包已做[独立解包加载检查](../../robots/Goose_V0.1/evidence/wheel_load_rc2.json)：Goose 和原有 Sai_Agent_001/002 模型可加载，默认机器人仍为 001。安装包只含运行所需模型/配置，不含 CAD、采购表和历史验证；完整工程资料以[Goose 导航](../../robots/Goose_V0.1/README.md)为准。

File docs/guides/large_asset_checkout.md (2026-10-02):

# 大型 Goose 资产的拉取

GitHub 交付快照使用 Git LFS 保存超过 100 MiB 的 Blender/OBJ 文件。LFS 指针保存原文件的 SHA256 和长度；CAD、图片、采购表及普通源文件仍位于原目录，未删减或改名。

在安装 Git LFS 的机器上拉取交付分支后执行：

```bash
git lfs install --local
git lfs pull
git lfs fsck
```

未拉取 LFS 时，对应文件是三行文本指针，不能直接拿来加载 Blender 或仿真。工程参数、验证证据中的 SHA256 均指展开后的原始资产，不是指针文本的哈希。

首次大型资产快照以远端已有提交 `80bff91f42343ff42733c96fb92abc7af5439972` 为父提交，以避开未发布本地历史中超过 GitHub 单文件限制的旧版本。主干交付随后从这个远端快照向前同步本地工程提交 `498b1e06` 的460件一体头壳训练检查点，并补充主页及自动检查。四个大型资产仍保持原始字节和 LFS 身份。PR 分支向前推进，不强推；本地 `codex/goose-stage-three-four` 原始历史及提交哈希不改写。

历史报告中引用的未发布本地提交仍指原本版本，不能假定 GitHub 快照包含这些历史对象。需重现历史模型时，使用保留的本地工程分支；当前交付的文件、原交接包资料、图片和采购表均在快照中。当前快照不代表第三、第四阶段或制造验收通过。

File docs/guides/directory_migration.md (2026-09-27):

# 目录迁移记录

迁移日期：2026-09-27。迁移前提交：`8a36c439ed1c1fe83e8f768ed42ff85b824181d4`。

本次按机器人归档资料、共享公共能力，共移动 334 个文件。
机器人 ID、默认 001、`sai_agent` 导入、`sai-agent` 命令与策略选择名称保留。
规则正文见[工程规范](../../sai_robots_engineering_rules.md)。

## 新旧路径

| 原目录 | 新目录 |
|---|---|
| `models` | `robots/Sai_Agent_001/models` |
| `policies` | `shared/policies` |
| `configs` | `shared/configs` |
| `experiments/stair_profiles` | `experiments/Sai_Agent_001/stair_profiles` |

逐个文件的例外映射见 [directory_migration.json](directory_migration.json)。
定位历史路径时，先查 `file_moves` 的完整匹配，再替换 `directory_moves` 的最长目录前缀。
旧提交、版本固定的外部接入仍使用其原布局；新版本调用者应使用 `model_root(robot_id)`
定位模型，不再拼接根目录 `models/`。

- 001 专属文档归入其 `design/`，真实图像归入其 `images/`，概念图归入 `design/concepts/`。
- 002 变更记录归入 `design/`，BREP 输入归入 `cad/source/`，STEP/STL 和导出报告归入 `cad/exports/`。
- 历史运行、机器人与引擎结果归入 001 的 `evidence/`；安装、CI 与发布证据归入 `docs/releases/evidence/`；共用后端/性能检查归入 `docs/validation/evidence/`。
- 命令脚本按模型、CAD、训练、评估、诊断用途归类；现有诊断回放与测试样本保持原名称。
- 新训练运行默认输出 `artifacts/<robot_id>/<run_id>/`，历史台账里的旧输出地址不改写。

交付 ONNX 对应的 `flat-v1.pt` 训练检查点归入 `experiments/Sai_Agent_001/flat_v1/`，
作为精选复现输入保留，运行 wheel 不携带训练检查点。

## 历史记录与资产

模型、网格、策略、CAD、建模输入、历史验证 JSON 与实验台账按移动前 SHA-256 核对。
这些历史文件的内容和内部哈希不改写；源码、实时文档、资源登记和打包引用更新到新路径。
实验 `stair_profiles` 中的早期 `descent60` 与交付策略的 `descent60` 哈希不同，分别保留。
`ascent60` 的实验快照与交付副本虽相同，仍保留其复现角色，不在本次整理中去重。
001 完整可编辑 CAD 未随原仓库交付，此次不补造源文件；002 的 STEP 只覆盖变更壳体和垫片。

## 验证

- 自动测试：15 项通过，覆盖原控制契约、机器人变体、源码/包资源定位、Godot 资产导出、默认 ID，以及评估不改写交付模型。
- 资产与历史记录：541 个模型、CAD、建模输入、策略、JSON/JSONL 文件的迁移前后 SHA-256 一致；独立审查另核对图像等共 553 个资产/记录文件，字节一致。
- 平地回归：001、002 各 8/8 项完整关节 MuJoCo 控制检查通过。
- 安装包：运行 wheel 构建并在全新环境安装，506 个条目；包含的资源逐项与源码比对一致，无 CAD、设计、图片、实验、历史证据或训练检查点。
- 打包复现：从源码分发重新构建 wheel，所有条目的内容与直接构建一致；安装环境的依赖兼容检查通过。
- CI 防护：新增实际安装 wheel 的模型、策略、模块/资源清单与字节检查；人为加入未入库临时模型的包会被拦截。
- 包内资源：两个机器人的完整/显示/精简模型、默认与两种显式实验策略、货物控制器均加载成功。
- Godot 启动：源码和安装包中的 001/002 共四次一秒 W 输入检查通过，各记录 51 个采样；安装包 001 使用省略 `--robot` 的默认入口。
- 文档与脚本：本地 Markdown 链接、全部 Python 源码语法、评估与模型处理的可用命令入口检查通过。
- 独立审查：无阻塞问题；旧证据文本路径和迁移文件数量两处文档问题已修正。评估生成模型与修正前的哈希、接触网格、27 组物理数组及平地指标完全一致。

此次启动检查使用本机已有 Godot `4.7.stable.official.5b4e0cb0f`，不是原文档中的 4.7.2；
它验证资源导入、启动和基本步进，不替代原有完整 Godot 性能/阶梯/货物验收。
GPU 训练、GPU 数值回放、CAD 布尔重建和 Unity 编辑器没有在此次目录迁移中重跑。
历史仿真验收与制造资料限制保持原有含义。
完整关节平地评估原先会把临时模型写回交付模型目录，导致评估后打包混入未审查资源。
已在独立修正中将临时场景及其接触网格保存到指定运行输出目录；不改变模型参数与评估标准。
外部项目若固定旧 Git 提交，继续使用原布局；升级本项目版本时须适配模型与共享策略新路径。

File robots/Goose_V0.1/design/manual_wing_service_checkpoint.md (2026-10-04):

# 手动翼形检修门与同版整机检查点

本版把自交修复后的身体曲壳、四处屋顶支承、颈部圆形开口、实际手动铰链和关闭保持件合入独立整机源。它替换460对象版的六片旧壳，并增加18件名义采购五金，形成**478显示对象、18主动轴、闭嘴19体SI、10.398672986kg条件质量**；比前版减轻32.089617g。其余器件、轴序、主连杆与质量预留保持。原460源与003运行包保留，新增CAD/SI没有冒充已冻结的训练版本。

这是带实际连接的结构检查点。有限几何与静力通过，**完整制造、电气、动力学及最终外观尚未放行**。翼门上沿仍有明显接缝，外露铰链也需最终审美与实体配合验收；本版图不称为一比一最终制造外观。

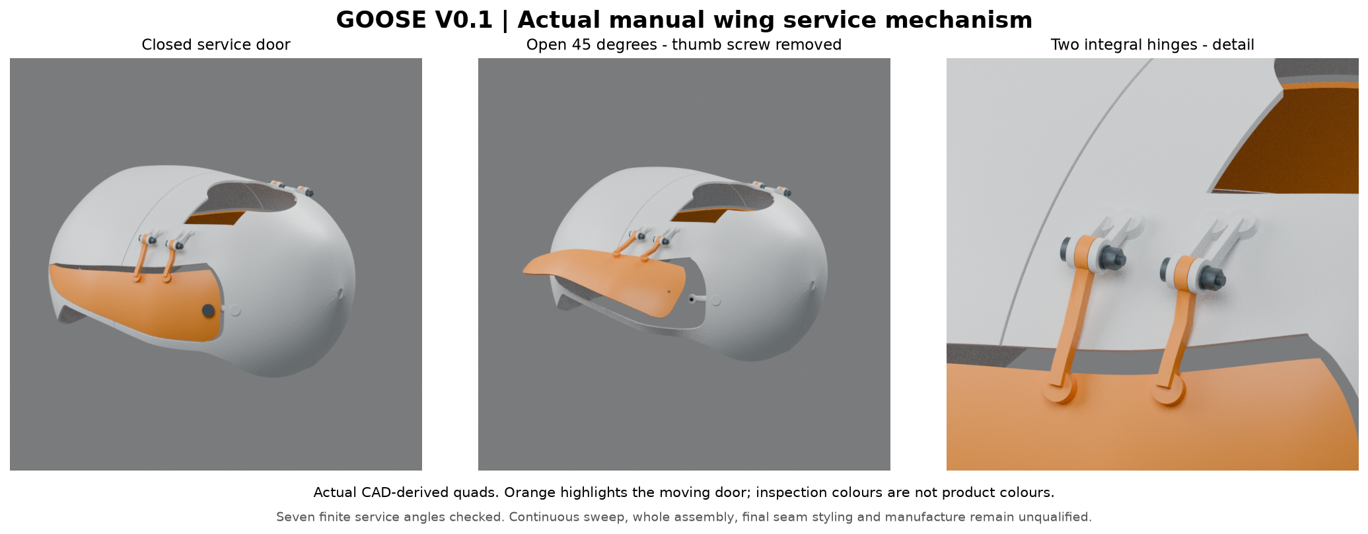
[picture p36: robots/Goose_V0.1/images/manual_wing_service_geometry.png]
实际源的关闭、45°开启与双铰链近景


图中橙色仅标识活动门片。图由24件CAD派生quad在Blender 4.0.2实际渲染，没有改几何或视口切面；开门图先移除该侧手拧螺钉和垫圈。

## 结构与装配关系

| 部位 | 当前名义构造与边界 |
|---|---|
| 固定壳 | 保留名义2.4mm曲壳，加入四处屋顶PETG凸台、M3热熔螺母底孔和半径44mm颈部开口；对接原有框架支承与名义五金 |
| 每侧双铰链 | 两轴中心X−5/+27mm，轴平行X；右Y−109/Z371mm、左侧镜像。活动桶4mm、两固定桶各2.5mm，两轴向间隙各0.25mm；总塑料叠层9.5mm |
| 铰链保持 | 四套[MISUMI MSB4.5-10轴肩螺钉](https://sg.misumi-ec.com/vona2/detail/110300249140/?HissuCode=MSB4.5-10)、M3垫圈及DIN985锁紧螺母。D4.5mm轴肩、L10mm、M3端螺纹，名义0.5mm轴向余隙；螺母在金属轴肩处锁紧，不能靠压紧塑料桶来消除余隙。见[原厂尺寸表](https://th.misumi-ec.com/pdf/fa/2010/p2_0209.pdf) |
| 打印转孔 | D4.8mm对应D4.5mm轴肩；0.3mm名义直径余隙未替代打印收缩、实际公差、旋转磨损与轴肩退刀槽检查 |
| 每门关闭保持 | 一件可取下的[DIN653-M3-8手拧螺钉](https://www.elesa-ganter.com/siteassets/PDF/EN/DIN%20653.pdf)、垫圈、Ruthex RX-M3x5.7与固定壳内部承接座；不是磁吸或仅靠摩擦。名义螺纹有效进入4.6mm，距螺母末端1.1mm；热熔安装、拔出力与拧紧力矩待资格 |
| 运行归属 | 两门运行时关闭，质量归torso，不增加执行器或策略轴。服务位仅用于检修；手拧件不是防丢的俘获螺钉 |

先将四处屋顶固定壳连接到原框架，再配装每侧双铰链轴肩螺钉、垫圈和锁紧螺母；确认门片自由转动后，装闭合插入件及手拧件。实际装配工具可达、框架/线束全路径、开门限位、局部承力和打印材料试件尚未通过，以上是名义关系而非已验证工艺。采购五金使用自建名义包络，螺纹简化；五金STL不用于打印成替代金属件。精确中国供货价格和交期仍待选定，表中没有虚填报价。

## 已完成的有限检查

| 检查 | 本版结果与限制 |
|---|---|
| 24件原生及交换 | 原生BREP及STEP回读独立小边/自交检查通过；quad全部四边面、闭合并核对体积，STL闭合/绕序/体积误差≤0.005 |
| 开合 | 左、右各0/15/30/45/60/75/90°，分别对同侧前、后固定壳；28个有限配对零交集，最小距离0.25mm。不是连续扫掠，也不覆盖全部内部零件 |
| 阳性对照 | 两侧活动门各与自身Common，恢复门体积；未把求交失败或无效输入的零值当作无干涉 |
| 屋顶支承 | 四件实际屋顶支承与四片新固定壳，共16个限定配对通过；不覆盖全机连接、全部孔边或工具路径 |
| 同源静力 | 含50g指定负载，嘴尖20N与中部50N各63工况，接触可行性与声明的关节上限通过；右膝最小余量分别0.056856/0.073253Nm，余量很窄，不能视为动态或持续热能力通过 |
| 全机原生输入盘点 | 449个已映射原生源：447通过、0拒绝、2未知（上下嘴壳检查超时）；另29个显示对象未在本次原生清单建立对应。未知不转为通过，未映射也不等于源码不存在 |
| 针对性测试 | 19项通过，覆盖几何构造尺寸、真实自交失败源、支臂碰壳失败源、闭合quad/查询控制、同版SI及现行相邻碰撞过滤；不是全机验收 |

29个未映射对象包括内联端塞、按钮、线缆、两片鞋边、17个厂商电机包络及两片柔性足底。其来源/用途需要分别归类；不能全部拿显示网格当打印源。

保留三种真实开发失败：[原始源及拒绝记录](../evidence/manual_wing_service_development_rejections.json)。自动同域面合并曾使左固定壳新增自交；较长活动支臂在45°与前壳交集4.220443mm³；较浅的关闭支承路径在关闭位交集1.392837mm³。当前构造分别保留有效原生分区、缩短外侧活动支臂和向内移动固定支承路径后重新检查。失败源用于回归，未进入当前装配。

## 同版文件入口

| 入口 | 内容 |
|---|---|
| [结构配置](../configs/manual_wing_service.json) | 转轴、固定/活动臂、底孔、名义五金及原厂资料 |
| [CAD及交换清单](../cad/exports/manual_wing_service/manifest.json) | 24件BREP/STEP/STL/quad、质量/完整惯量、名义接触与哈希 |
| [478对象整机源](../cad/source/manual_wing_service/assembly_scene.json) | 与旧源分离的实际装配；全部四色共用 |
| [19体完整SI](../evidence/manual_wing_service_parameters.json) | 588项质量台账、19体COM/完整惯量、原18轴序与枢轴 |
| [采购增量XLSX](../hardware/manual_wing_service_bom.xlsx) · [CSV](../hardware/manual_wing_service_bom.csv) · [逐体SI CSV](../hardware/manual_wing_service_body_parameters.csv) | 六件打印替换与18件名义采购件；其余整机BOM/预留保留 |
| [有限配合与静力证据](../evidence/manual_wing_service_checks.json) | 源绑定的24件、28开合、16支承、126静力结果与限制 |
| [全机原生盘点](../evidence/manual_wing_service_native_inventory.json) | 有界进程隔离查询；超时/未映射与通过分别记录 |
| [Blender检查图身份](../evidence/manual_wing_service_blender_views.json) · [组合图身份](../evidence/manual_wing_service_geometry_figure.json) | 实际quad、渲染参数、各图哈希 |
| [四色配置](../configs/microduck_color_blocking_manual_wing_service.json) · [四色渲染身份](../evidence/microduck_color_blocking_manual_wing_service_render_manifest.json) | 同几何、同镜头/灯光、不同材料角色，零几何修改器 |
| [交付一致性核查](../evidence/manual_wing_service_delivery_audit.json) | 输入/输出哈希、相对链接、尺寸与003身份保持 |

| Cream | Graphite |
|---|---|
| Cream | Graphite |
| Lavender | Sky |
| Lavender | Sky |

闭合零位显示网格包围尺寸43.38×26.7087×64.2034cm，含显示平移；该尺寸不是活动包络。彩图的外露支臂和上沿接缝来自本版真实候选结构，没有通过渲染遮掉。

## 返回整机后的下一退出条件

此处收束局部铰链探索，返回整机：补齐原生输入归属、全域壁厚/连接承力与线束/检修空间；闭合精确驱动电压和回馈、保护与独立急停；随后生成与本版CAD/SI相符的具名运行模型，并复查指定物夹取、拖拽和转向。连续门扫掠、最终门缝与打印试件列入该整体资格，不继续以局部图替代整机推进。

[11凸包003运行入口](task_proxy_11_v1.md)保持原质量和源身份，55对内部组合仅9对相邻连接处忽略，其余46对保留，头与躯干继续碰撞；地面、物品和其他机器人不忽略。运行代理例外不会豁免上述真实CAD检查。新硬件条件质量10.398672986kg不能直接替换003的10.430690821kg动力学身份。

## 复现顺序

需Python3.12、build123d0.11.1/OCP7.9.3.1、NumPy、SciPy、trimesh、Matplotlib、openpyxl；实际渲染另需Blender4.0.2。每条完成后再执行下一条，拒绝项不得跳过后覆盖证据。

```bash
env OPENBLAS_NUM_THREADS=1 PYTHONPATH=src .venv/bin/python scripts/cad/build_goose_manual_wing_service.py
env OPENBLAS_NUM_THREADS=1 PYTHONPATH=src .venv/bin/python scripts/diagnostics/check_goose_manual_wing_service.py
env OPENBLAS_NUM_THREADS=1 PYTHONPATH=src .venv/bin/python scripts/diagnostics/check_goose_scene_native_integrity.py --scene cad/source/manual_wing_service/assembly_scene.json --output evidence/manual_wing_service_native_inventory.json --seconds-per-part 10 --seconds-total 300
env PYTHONPATH=src .venv/bin/python scripts/diagnostics/build_goose_manual_wing_service_bom.py
blender -b --factory-startup --threads 8 --python-exit-code 2 --python scripts/models/render_goose_manual_wing_service_views.py -- --root "$PWD"
.venv/bin/python scripts/models/render_goose_manual_wing_service.py
blender -b --factory-startup --threads 16 --python-exit-code 2 --python scripts/models/render_goose_color_blocking_manual_wing_service.py -- --scene robots/Goose_V0.1/cad/source/manual_wing_service/assembly_scene.json --geometry-root robots/Goose_V0.1 --config robots/Goose_V0.1/configs/microduck_color_blocking_manual_wing_service.json --output robots/Goose_V0.1/images/microduck_color_blocking_manual_wing_service --manifest robots/Goose_V0.1/evidence/microduck_color_blocking_manual_wing_service_render_manifest.json --resolution 1000 --samples 64
env OPENBLAS_NUM_THREADS=1 PYTHONPATH=src .venv/bin/python -m pytest -q tests/test_goose_manual_wing_service.py tests/test_native_cad_skin_integrity.py tests/test_native_cad_query_sanity.py tests/test_goose_collision_filters.py
```

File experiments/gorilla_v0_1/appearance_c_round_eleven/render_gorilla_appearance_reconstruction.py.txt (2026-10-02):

#!/usr/bin/env python3
"""Render/export the actual C appearance mesh with all surface bevels applied."""
from __future__ import annotations

import argparse
import hashlib
import json
import math
import os
from pathlib import Path
import subprocess
import sys

ROOT=Path(__file__).resolve().parents[2]
ROBOT=ROOT/"robots/gorilla_v0_1"
BLENDER_ROOT=Path("/home/ethan/Softwares/blender-local/root")
EXPORT=ROBOT/"cad/exports/appearance_c"
IMAGES=ROBOT/"images"

def sha(p):return hashlib.sha256(p.read_bytes()).hexdigest()

def arguments():
    p=argparse.ArgumentParser(description=__doc__)
    p.add_argument("--scene",type=Path,default=ROBOT/"cad/source/appearance_c_scene.json")
    p.add_argument("--resolution",type=int,default=900)
    p.add_argument("--samples",type=int,default=48)
    p.add_argument("--views",default="front,left,rear,top,threequarter")
    p.add_argument("--no-export",action="store_true")
    p.add_argument("--tag",default="appearance_c")
    argv=sys.argv[sys.argv.index("--")+1:] if "--" in sys.argv else None
    return p.parse_args(argv)

def wrapper(args):
    env=os.environ.copy()
    env["LD_LIBRARY_PATH"]=":".join(str(BLENDER_ROOT/p) for p in (
        "usr/lib","usr/lib/aarch64-linux-gnu","usr/lib/aarch64-linux-gnu/lapack","usr/lib/aarch64-linux-gnu/blas"))
    env["BLENDER_SYSTEM_SCRIPTS"]=str(BLENDER_ROOT/"usr/share/blender/scripts")
    env["BLENDER_SYSTEM_DATAFILES"]=str(BLENDER_ROOT/"usr/share/blender/datafiles")
    env["PYTHONHOME"]="/usr";env["PYTHONNOUSERSITE"]="1"
    env["PYTHONPATH"]=str(ROOT/".venv/lib/python3.12/site-packages")
    EXPORT.mkdir(parents=True,exist_ok=True);IMAGES.mkdir(parents=True,exist_ok=True)
    cmd=[str(BLENDER_ROOT/"usr/bin/blender"),"-b","--threads","12","--python-exit-code","1","--python",str(Path(__file__).resolve()),"--",
         "--scene",str(args.scene),"--resolution",str(args.resolution),"--samples",str(args.samples),"--views",args.views,"--tag",args.tag]
    if args.no_export:cmd.append("--no-export")
    logdir=ROOT/"artifacts/gorilla_v0_1/appearance_c_render";logdir.mkdir(parents=True,exist_ok=True)
    log=logdir/f"{args.tag}.log"
    with log.open("w") as f:
        result=subprocess.run(cmd,env=env,stdout=f,stderr=subprocess.STDOUT)
    if result.returncode:
        print(log.read_text()[-6000:]);raise RuntimeError(f"Blender render failed; log {log}")
    from PIL import Image,ImageDraw,ImageFont
    n=args.resolution;views=args.views.split(",")
    paths=[IMAGES/f"{args.tag}_{v}.png" for v in views]
    if all(v in views for v in ("front","left","rear","top")):
        sheet=Image.new("RGB",(2*n,2*n+110),"white");draw=ImageDraw.Draw(sheet)
        try:font=ImageFont.truetype("/usr/share/fonts/truetype/dejavu/DejaVuSans.ttf",max(16,n//42))
        except OSError:font=ImageFont.load_default()
        for name,c,r in (("front",0,0),("left",1,0),("rear",0,1),("top",1,1)):
            im=Image.open(IMAGES/f"{args.tag}_{name}.png").convert("RGBA")
            sheet.paste(im,(c*n,55+r*n),im)
            draw.text((c*n+20,55+r*n+12),name.upper(),fill="#2b3e51",font=font)
        draw.text((20,15),"Gorilla V0.1 / AA3 appearance reconstruction C / actual 3D mesh",fill="#2b3e51",font=font)
        draw.text((20,2*n+68),"Source-bound appearance iteration; not yet accepted. No physical approval.",fill="#2b3e51",font=font)
        out=IMAGES/f"{args.tag}_four_view.png";sheet.save(out);paths.append(out)
    source=json.loads(args.scene.read_text())
    manifest={"schema":"gorilla_appearance_render_v2","robot_id":"gorilla_v0_1","checkpoint_id":"gorilla_appearance_c",
        "scene_path":str(args.scene.relative_to(ROOT)),"scene_sha256":sha(args.scene),"spec_path":source["spec_path"],"spec_sha256":source["spec_sha256"],
        "image_authority_sha256":source["image_sha256"],"renderer_script_path":str(Path(__file__).resolve().relative_to(ROOT)),"renderer_script_sha256":sha(Path(__file__).resolve()),
        "renderer":"Blender 4.0.2 Cycles CPU","resolution":n,"samples":args.samples,
        "source_scope":"Editable control meshes with recorded bevel parameters; modifiers applied identically before rendering and export.",
        "views":"Same actual source geometry. Standard four views use the neutral pose; TOP is full-body vertical orthographic. Extra reference cameras and the explicitly recorded illustrative top_pose_a are diagnostics. top_upper_assembly isolation cannot establish whole-body acceptance.",
        "post_processing":"Only alpha compositing onto a white labeled contact sheet; no shape, color or geometry correction.",
        "images":[{"path":str(p.relative_to(ROOT)),"sha256":sha(p)} for p in paths],
        "camera_definitions":json.loads((EXPORT/f"{args.tag}_camera_manifest.json").read_text()),
        "appearance_accepted":False,"physics_accepted":False}
    if not args.no_export:
        manifest["exports"]=[{"path":str(p.relative_to(ROOT)),"sha256":sha(p)} for p in (ROBOT/"cad/source/appearance_c.blend",EXPORT/"appearance_c.glb",EXPORT/"evaluated_mesh_manifest.json")]
    (EXPORT/f"{args.tag}_render_manifest.json").write_text(json.dumps(manifest,indent=2)+"\n")
    print(json.dumps({"render_manifest":str(EXPORT/f"{args.tag}_render_manifest.json"),"images":[str(p) for p in paths]}))

def blender_render(args):
    import bpy
    from mathutils import Vector,Matrix
    data=json.loads(args.scene.read_text())
    for item in [{"path":data["spec_path"],"sha256":data["spec_sha256"]},{"path":data["appearance_authority_path"],"sha256":data["image_sha256"]},*data["build_inputs"]]:
        if sha(ROOT/item["path"])!=item["sha256"]:raise ValueError("Stale input: "+item["path"])
    bpy.ops.object.select_all(action="SELECT");bpy.ops.object.delete(use_global=False)
    scene=bpy.context.scene;scene.render.engine="CYCLES";scene.cycles.device="CPU"
    scene.cycles.samples=args.samples;scene.cycles.use_denoising=False
    bpy.context.preferences.filepaths.save_version=0
    scene.render.resolution_x=scene.render.resolution_y=args.resolution;scene.render.resolution_percentage=100
    scene.render.image_settings.file_format="PNG";scene.render.image_settings.color_mode="RGBA"
    scene.render.film_transparent=True
    scene.view_settings.view_transform="Standard";scene.view_settings.look="None"
    scene.view_settings.exposure=-.35;scene.view_settings.gamma=1
    world=bpy.data.worlds.new("white_studio");world.use_nodes=True
    world.node_tree.nodes["Background"].inputs["Color"].default_value=(1,1,1,1)
    world.node_tree.nodes["Background"].inputs["Strength"].default_value=.30;scene.world=world
    def linear(c):return c/12.92 if c<=.04045 else ((c+.055)/1.055)**2.4
    materials={};objects=[];evaluated=[]
    for part in data["parts"]:
        mesh=bpy.data.meshes.new(part["name"]+"_mesh");mesh.from_pydata(part["vertices_world_m"],[],part["faces"]);mesh.update()
        ob=bpy.data.objects.new(part["name"],mesh);bpy.context.collection.objects.link(ob)
        ob["body"]=part["body"];ob["role"]=part["role"];ob["physical_mass_assigned"]=False
        color=tuple(linear(c) for c in part["rgba"][:3])+(part["rgba"][3],)
        key=(tuple(part["rgba"]),part["role"])
        if key not in materials:
            mat=bpy.data.materials.new("paint_"+str(len(materials)));mat.use_nodes=True;mat.diffuse_color=color
            bsdf=mat.node_tree.nodes.get("Principled BSDF");bsdf.inputs["Base Color"].default_value=color
            bsdf.inputs["Metallic"].default_value=.25 if part["role"]=="visible_mechanism" else .12
            bsdf.inputs["Roughness"].default_value=.32 if part["role"]=="visible_mechanism" else .28
            materials[key]=mat
        mesh.materials.append(materials[key])
        if "face_rgba" in part:
            if len(part["face_rgba"])!=len(mesh.polygons):raise ValueError("Face palette mismatch: "+part["name"])
            local_slots={tuple(part["rgba"]):0}
            for face,rgba in zip(mesh.polygons,part["face_rgba"]):
                rgba_key=tuple(rgba)
                if rgba_key not in local_slots:
                    mk=(rgba_key,part["role"])
                    if mk not in materials:
                        mat=bpy.data.materials.new("paint_"+str(len(materials)));mat.use_nodes=True
                        color_face=tuple(linear(c) for c in rgba[:3])+(rgba[3],);mat.diffuse_color=color_face
                        bsdf=mat.node_tree.nodes.get("Principled BSDF");bsdf.inputs["Base Color"].default_value=color_face
                        bsdf.inputs["Metallic"].default_value=.12;bsdf.inputs["Roughness"].default_value=.28
                        materials[mk]=mat
                    local_slots[rgba_key]=len(mesh.materials);mesh.materials.append(materials[mk])
                face.material_index=local_slots[rgba_key]
        for p in mesh.polygons:p.use_smooth=part["surface_shading"] in ("mechanical_smooth","curved_hard_surface")
        mesh.use_auto_smooth=True;mesh.auto_smooth_angle=math.radians(part.get("auto_smooth_angle_deg",45))
        # Separate observed long face bands while smoothing along their
        # sampled curved height. A single low angle made every sampled Z
        # contour turn into an unintended horizontal polygon crease.
        sharp_rings=part.get("longitudinal_sharp_ring_indices",[])
        if sharp_rings:
            ring_n=part["ring_vertex_count"]
            for edge in mesh.edges:
                a,b=edge.vertices
                if abs(a-b)==ring_n and a%ring_n==b%ring_n and a%ring_n in sharp_rings:
                    edge.use_edge_sharp=True
        explicit_sharp={tuple(sorted(pair)) for pair in part.get("sharp_surface_edge_pairs",[])}
        if explicit_sharp:
            for edge in mesh.edges:
                if tuple(sorted(edge.vertices)) in explicit_sharp:edge.use_edge_sharp=True
        bpy.context.view_layer.objects.active=ob;ob.select_set(True)
        if part["edge_bevel_m"]>0:
            mod=ob.modifiers.new("source_recorded_bevel","BEVEL");mod.width=part["edge_bevel_m"]
            mod.segments=part["bevel_segments"];mod.limit_method="ANGLE";mod.angle_limit=math.radians(25)
            mod.use_clamp_overlap=True
            bpy.ops.object.modifier_apply(modifier=mod.name)
        if part["surface_shading"]!="curved_hard_surface":
            mod=ob.modifiers.new("surface_weighted_normals","WEIGHTED_NORMAL");mod.keep_sharp=True;mod.weight=50
            bpy.ops.object.modifier_apply(modifier=mod.name)
        ob.select_set(False);objects.append(ob)
        evaluated.append({"name":ob.name,"body":part["body"],"vertices":len(ob.data.vertices),"polygons":len(ob.data.polygons)})
    EXPORT.mkdir(parents=True,exist_ok=True);IMAGES.mkdir(parents=True,exist_ok=True)
    scene["source_scene_sha256"]=sha(args.scene);scene["image_authority_sha256"]=data["image_sha256"]
    scene["appearance_accepted"]=False;scene["physics_accepted"]=False
    if not args.no_export:
        for ob in objects:ob.select_set(True)
        bpy.context.view_layer.objects.active=objects[0]
        bpy.ops.export_scene.gltf(filepath=str(EXPORT/"appearance_c.glb"),export_format="GLB",use_selection=True,export_yup=True)
        bpy.ops.object.select_all(action="DESELECT")
        (EXPORT/"evaluated_mesh_manifest.json").write_text(json.dumps({"scene_sha256":sha(args.scene),"bevels_applied":True,"parts":evaluated},indent=2)+"\n")
    bpy.ops.mesh.primitive_plane_add(size=200,location=(0,0,-.004))
    floor=bpy.context.object;floor.name="studio_shadow_floor";floor.is_shadow_catcher=True
    floor_mat=bpy.data.materials.new("studio_floor");floor_mat.diffuse_color=(.95,.95,.95,1);floor.data.materials.append(floor_mat)
    def light(name,pos,power,size):
        ld=bpy.data.lights.new(name,"AREA");ld.energy=power;ld.shape="DISK";ld.size=size
        ob=bpy.data.objects.new(name,ld);bpy.context.collection.objects.link(ob);ob.location=pos
        ob.rotation_euler=(Vector((0,0,1.4))-ob.location).to_track_quat("-Z","Y").to_euler()
    light("key_front",(4,-3,6),250,4);light("fill_left",(1,4,4),180,4);light("rear_soft",(-4,1,5),250,4)
    cam=bpy.data.cameras.new("source_orthographic_camera");ob=bpy.data.objects.new("source_orthographic_camera",cam)
    bpy.context.collection.objects.link(ob);scene.camera=ob;cam.type="ORTHO"
    positions={"front":((8,0,1.325),(0,0,1.325),3.04),"left":((0,8,1.325),(0,0,1.325),3.04),
               "rear":((-8,0,1.325),(0,0,1.325),3.04),"top":((0,0,8),(.1,0,0),2.26),
               "threequarter":((4,-6,3.7),(0,0,1.325),3.10),
               "chest_detail":((6,-1,2.5),(.12,0,2.22),1.38),
               "hand_detail":((5,3,2),(.13,.84,1.04),.63),
               "leg_detail":((5,3,1.4),(.1,.44,.69),1.31),
               "top_reference":((2.80,0,4.50),(.1,0,1.50),2.55),
               "front_reference":((8,0,2.20),(0,0,1.325),3.04),
               "top_pose_a":((.362,0,4.50),(.1,0,1.50),2.55),
               "top_near_vertical":((.1,0,5.0),(.1,0,1.45),2.55),
               "top_upper_assembly":((2.80,0,4.50),(.1,0,1.82),2.40)}
    ob.location=(4,-6,3.7);ob.rotation_euler=(Vector((0,0,1.325))-ob.location).to_track_quat("-Z","Y").to_euler();cam.ortho_scale=3.1
    if not args.no_export:bpy.ops.wm.save_as_mainfile(filepath=str(ROBOT/"cad/source/appearance_c.blend"))
    camera_records=[]
    for name in args.views.split(","):
        pos,target,scale=positions[name];ob.location=pos
        ob.rotation_euler=(Vector(target)-ob.location).to_track_quat("-Z","Y").to_euler()
        cam.type="ORTHO";cam.ortho_scale=scale
        if name=="top":ob.rotation_euler=(0,0,math.pi/2)
        if name in ("top_reference","top_near_vertical","top_upper_assembly","top_pose_a"):
            cam.type="PERSP";cam.lens=58 if name=="top_near_vertical" else 45;cam.sensor_width=36
            if name=="top_near_vertical":ob.rotation_euler=(0,0,math.pi/2)
        hidden=[]
        pose=None
        if name=="top_pose_a":
            spec=json.loads((ROOT/data["spec_path"]).read_text());affected=[]
            # Candidate display pose only: each complete arm stays rigidly
            # connected at its existing shoulder. No foot translation/hiding.
            for side in ("left","right"):
                pivot=Vector(spec["points_world_m"][side+"_shoulder"])
                transform=Matrix.Translation(pivot)@Matrix.Rotation(math.radians(-50),4,"Y")@Matrix.Translation(-pivot)
                for mesh in objects:
                    body=mesh["body"]
                    if body.startswith(side+"_") and any(label in body for label in ("upper_arm","forearm","palm","finger","thumb")):
                        mesh.matrix_world=transform;affected.append(mesh.name)
            pose={"scope":"Illustrative shoulder display pose, not a physical joint contract or validated feasible posture.",
                  "axis_world":[0,1,0],"rotation_deg":-50,"description":"Both complete arms forward about the source shoulder pivots; all legs and feet remain neutral.",
                  "affected_mesh_names":affected}
        if name=="top_upper_assembly":
            for mesh in objects:
                body=mesh["body"]
                if any(label in body for label in ("thigh","middle_shank","distal_shank","foot","hip_","knee_","ankle_")):
                    mesh.hide_render=True;hidden.append(mesh.name)
        camera_records.append({"view":name,"projection":cam.type,"position_m":list(pos),"target_m":list(target),
            "rotation_euler_rad":list(ob.rotation_euler),"ortho_scale_m":scale if cam.type=="ORTHO" else None,
            "lens_mm":cam.lens if cam.type=="PERSP" else None,"sensor_width_mm":cam.sensor_width if cam.type=="PERSP" else None,
            "assembly_isolation":name=="top_upper_assembly","hidden_mesh_names":hidden,
            "display_pose":pose,
            "interpretation":"Uncalibrated artwork camera/pose candidate; not appearance acceptance." if name.startswith("top_") or name.endswith("_reference") else "Actual neutral geometry."})
        scene.render.filepath=str(IMAGES/f"{args.tag}_{name}.png")
        bpy.ops.render.render(write_still=True)
        for mesh in objects:mesh.hide_render=False;mesh.matrix_world=Matrix.Identity(4)
    (EXPORT/f"{args.tag}_camera_manifest.json").write_text(json.dumps(camera_records,indent=2)+"\n")

if __name__=="__main__":
    args=arguments()
    try:import bpy
    except ImportError:wrapper(args)
    else:blender_render(args)

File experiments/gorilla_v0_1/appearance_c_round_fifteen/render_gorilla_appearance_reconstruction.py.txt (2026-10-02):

#!/usr/bin/env python3
"""Render/export the actual C appearance mesh with all surface bevels applied."""
from __future__ import annotations

import argparse
import hashlib
import json
import math
import os
from pathlib import Path
import subprocess
import sys

ROOT=Path(__file__).resolve().parents[2]
ROBOT=ROOT/"robots/gorilla_v0_1"
BLENDER_ROOT=Path("/home/ethan/Softwares/blender-local/root")
EXPORT=ROBOT/"cad/exports/appearance_c"
IMAGES=ROBOT/"images"

def sha(p):return hashlib.sha256(p.read_bytes()).hexdigest()

def arguments():
    p=argparse.ArgumentParser(description=__doc__)
    p.add_argument("--scene",type=Path,default=ROBOT/"cad/source/appearance_c_scene.json")
    p.add_argument("--resolution",type=int,default=900)
    p.add_argument("--samples",type=int,default=48)
    p.add_argument("--views",default="front,left,rear,top,threequarter")
    p.add_argument("--no-export",action="store_true")
    p.add_argument("--tag",default="appearance_c")
    argv=sys.argv[sys.argv.index("--")+1:] if "--" in sys.argv else None
    return p.parse_args(argv)

def wrapper(args):
    env=os.environ.copy()
    env["LD_LIBRARY_PATH"]=":".join(str(BLENDER_ROOT/p) for p in (
        "usr/lib","usr/lib/aarch64-linux-gnu","usr/lib/aarch64-linux-gnu/lapack","usr/lib/aarch64-linux-gnu/blas"))
    env["BLENDER_SYSTEM_SCRIPTS"]=str(BLENDER_ROOT/"usr/share/blender/scripts")
    env["BLENDER_SYSTEM_DATAFILES"]=str(BLENDER_ROOT/"usr/share/blender/datafiles")
    env["PYTHONHOME"]="/usr";env["PYTHONNOUSERSITE"]="1"
    env["PYTHONPATH"]=str(ROOT/".venv/lib/python3.12/site-packages")
    EXPORT.mkdir(parents=True,exist_ok=True);IMAGES.mkdir(parents=True,exist_ok=True)
    cmd=[str(BLENDER_ROOT/"usr/bin/blender"),"-b","--threads","12","--python-exit-code","1","--python",str(Path(__file__).resolve()),"--",
         "--scene",str(args.scene),"--resolution",str(args.resolution),"--samples",str(args.samples),"--views",args.views,"--tag",args.tag]
    if args.no_export:cmd.append("--no-export")
    logdir=ROOT/"artifacts/gorilla_v0_1/appearance_c_render";logdir.mkdir(parents=True,exist_ok=True)
    log=logdir/f"{args.tag}.log"
    with log.open("w") as f:
        result=subprocess.run(cmd,env=env,stdout=f,stderr=subprocess.STDOUT)
    if result.returncode:
        print(log.read_text()[-6000:]);raise RuntimeError(f"Blender render failed; log {log}")
    from PIL import Image,ImageDraw,ImageFont
    n=args.resolution;views=args.views.split(",")
    paths=[IMAGES/f"{args.tag}_{v}.png" for v in views]
    if all(v in views for v in ("front","left","rear","top")):
        sheet=Image.new("RGB",(2*n,2*n+110),"white");draw=ImageDraw.Draw(sheet)
        try:font=ImageFont.truetype("/usr/share/fonts/truetype/dejavu/DejaVuSans.ttf",max(16,n//42))
        except OSError:font=ImageFont.load_default()
        for name,c,r in (("front",0,0),("left",1,0),("rear",0,1),("top",1,1)):
            im=Image.open(IMAGES/f"{args.tag}_{name}.png").convert("RGBA")
            sheet.paste(im,(c*n,55+r*n),im)
            draw.text((c*n+20,55+r*n+12),name.upper(),fill="#2b3e51",font=font)
        draw.text((20,15),"Gorilla V0.1 / AA3 appearance reconstruction C / actual 3D mesh",fill="#2b3e51",font=font)
        draw.text((20,2*n+68),"Source-bound appearance iteration; not yet accepted. No physical approval.",fill="#2b3e51",font=font)
        out=IMAGES/f"{args.tag}_four_view.png";sheet.save(out);paths.append(out)
    source=json.loads(args.scene.read_text())
    manifest={"schema":"gorilla_appearance_render_v2","robot_id":"gorilla_v0_1","checkpoint_id":"gorilla_appearance_c",
        "scene_path":str(args.scene.relative_to(ROOT)),"scene_sha256":sha(args.scene),"spec_path":source["spec_path"],"spec_sha256":source["spec_sha256"],
        "image_authority_sha256":source["image_sha256"],"renderer_script_path":str(Path(__file__).resolve().relative_to(ROOT)),"renderer_script_sha256":sha(Path(__file__).resolve()),
        "renderer":"Blender 4.0.2 Cycles CPU","resolution":n,"samples":args.samples,
        "source_scope":"Editable control meshes with recorded bevel parameters; modifiers applied identically before rendering and export.",
        "views":"Same actual source geometry. Standard four views use the neutral pose; TOP is full-body vertical orthographic. Extra reference cameras and illustrative poses are diagnostics. foot_folded_left is an isolated unloaded mesh/lock probe with hidden geometry and no studio floor, not whole-robot contact or gait evidence. Assembly isolation cannot establish whole-body acceptance.",
        "post_processing":"Only alpha compositing onto a white labeled contact sheet; no shape, color or geometry correction.",
        "images":[{"path":str(p.relative_to(ROOT)),"sha256":sha(p)} for p in paths],
        "camera_definitions":json.loads((EXPORT/f"{args.tag}_camera_manifest.json").read_text()),
        "appearance_accepted":False,"physics_accepted":False}
    if not args.no_export:
        manifest["exports"]=[{"path":str(p.relative_to(ROOT)),"sha256":sha(p)} for p in (ROBOT/"cad/source/appearance_c.blend",EXPORT/"appearance_c.glb",EXPORT/"evaluated_mesh_manifest.json")]
    (EXPORT/f"{args.tag}_render_manifest.json").write_text(json.dumps(manifest,indent=2)+"\n")
    print(json.dumps({"render_manifest":str(EXPORT/f"{args.tag}_render_manifest.json"),"images":[str(p) for p in paths]}))

def blender_render(args):
    import bpy
    from mathutils import Vector,Matrix
    data=json.loads(args.scene.read_text())
    for item in [{"path":data["spec_path"],"sha256":data["spec_sha256"]},{"path":data["appearance_authority_path"],"sha256":data["image_sha256"]},*data["build_inputs"]]:
        if sha(ROOT/item["path"])!=item["sha256"]:raise ValueError("Stale input: "+item["path"])
    bpy.ops.object.select_all(action="SELECT");bpy.ops.object.delete(use_global=False)
    scene=bpy.context.scene;scene.render.engine="CYCLES";scene.cycles.device="CPU"
    scene.cycles.samples=args.samples;scene.cycles.use_denoising=False
    bpy.context.preferences.filepaths.save_version=0
    scene.render.resolution_x=scene.render.resolution_y=args.resolution;scene.render.resolution_percentage=100
    scene.render.image_settings.file_format="PNG";scene.render.image_settings.color_mode="RGBA"
    scene.render.film_transparent=True
    scene.view_settings.view_transform="Standard";scene.view_settings.look="None"
    scene.view_settings.exposure=-.35;scene.view_settings.gamma=1
    world=bpy.data.worlds.new("white_studio");world.use_nodes=True
    world.node_tree.nodes["Background"].inputs["Color"].default_value=(1,1,1,1)
    world.node_tree.nodes["Background"].inputs["Strength"].default_value=.30;scene.world=world
    def linear(c):return c/12.92 if c<=.04045 else ((c+.055)/1.055)**2.4
    materials={};objects=[];evaluated=[];foot_parts={}
    for part in data["parts"]:
        mesh=bpy.data.meshes.new(part["name"]+"_mesh");mesh.from_pydata(part["vertices_world_m"],[],part["faces"]);mesh.update()
        ob=bpy.data.objects.new(part["name"],mesh);bpy.context.collection.objects.link(ob)
        ob["body"]=part["body"];ob["role"]=part["role"];ob["physical_mass_assigned"]=False
        ob["structure_view_visible"]=part.get("structure_view_visible",False)
        if "composite_foot_group" in part:
            foot_parts[ob.name]=part
        color=tuple(linear(c) for c in part["rgba"][:3])+(part["rgba"][3],)
        surface_material=part.get("surface_material",{})
        key=(tuple(part["rgba"]),part["role"],tuple(sorted(surface_material.items())))
        if key not in materials:
            mat=bpy.data.materials.new("paint_"+str(len(materials)));mat.use_nodes=True;mat.diffuse_color=color
            bsdf=mat.node_tree.nodes.get("Principled BSDF");bsdf.inputs["Base Color"].default_value=color
            bsdf.inputs["Metallic"].default_value=.25 if part["role"]=="visible_mechanism" else .12
            bsdf.inputs["Roughness"].default_value=.32 if part["role"]=="visible_mechanism" else .28
            if "metallic" in surface_material:bsdf.inputs["Metallic"].default_value=surface_material["metallic"]
            if "roughness" in surface_material:bsdf.inputs["Roughness"].default_value=surface_material["roughness"]
            materials[key]=mat
        mesh.materials.append(materials[key])
        if "face_rgba" in part:
            if len(part["face_rgba"])!=len(mesh.polygons):raise ValueError("Face palette mismatch: "+part["name"])
            local_slots={tuple(part["rgba"]):0}
            for face,rgba in zip(mesh.polygons,part["face_rgba"]):
                rgba_key=tuple(rgba)
                if rgba_key not in local_slots:
                    mk=(rgba_key,part["role"])
                    if mk not in materials:
                        mat=bpy.data.materials.new("paint_"+str(len(materials)));mat.use_nodes=True
                        color_face=tuple(linear(c) for c in rgba[:3])+(rgba[3],);mat.diffuse_color=color_face
                        bsdf=mat.node_tree.nodes.get("Principled BSDF");bsdf.inputs["Base Color"].default_value=color_face
                        bsdf.inputs["Metallic"].default_value=.12;bsdf.inputs["Roughness"].default_value=.28
                        materials[mk]=mat
                    local_slots[rgba_key]=len(mesh.materials);mesh.materials.append(materials[mk])
                face.material_index=local_slots[rgba_key]
        for p in mesh.polygons:p.use_smooth=part["surface_shading"] in ("mechanical_smooth","curved_hard_surface")
        mesh.use_auto_smooth=True;mesh.auto_smooth_angle=math.radians(part.get("auto_smooth_angle_deg",45))
        # Separate observed long face bands while smoothing along their
        # sampled curved height. A single low angle made every sampled Z
        # contour turn into an unintended horizontal polygon crease.
        sharp_rings=part.get("longitudinal_sharp_ring_indices",[])
        if sharp_rings:
            ring_n=part["ring_vertex_count"]
            for edge in mesh.edges:
                a,b=edge.vertices
                if abs(a-b)==ring_n and a%ring_n==b%ring_n and a%ring_n in sharp_rings:
                    edge.use_edge_sharp=True
        explicit_sharp={tuple(sorted(pair)) for pair in part.get("sharp_surface_edge_pairs",[])}
        if explicit_sharp:
            for edge in mesh.edges:
                if tuple(sorted(edge.vertices)) in explicit_sharp:edge.use_edge_sharp=True
        bpy.context.view_layer.objects.active=ob;ob.select_set(True)
        if part["edge_bevel_m"]>0:
            mod=ob.modifiers.new("source_recorded_bevel","BEVEL");mod.width=part["edge_bevel_m"]
            mod.segments=part["bevel_segments"];mod.limit_method="ANGLE";mod.angle_limit=math.radians(25)
            mod.use_clamp_overlap=True
            bpy.ops.object.modifier_apply(modifier=mod.name)
        if part["surface_shading"]!="curved_hard_surface":
            mod=ob.modifiers.new("surface_weighted_normals","WEIGHTED_NORMAL");mod.keep_sharp=True;mod.weight=50
            bpy.ops.object.modifier_apply(modifier=mod.name)
        ob.select_set(False);objects.append(ob)
        evaluated.append({"name":ob.name,"body":part["body"],"vertices":len(ob.data.vertices),"polygons":len(ob.data.polygons)})
    EXPORT.mkdir(parents=True,exist_ok=True);IMAGES.mkdir(parents=True,exist_ok=True)
    scene["source_scene_sha256"]=sha(args.scene);scene["image_authority_sha256"]=data["image_sha256"]
    scene["appearance_accepted"]=False;scene["physics_accepted"]=False
    if not args.no_export:
        for ob in objects:ob.select_set(True)
        bpy.context.view_layer.objects.active=objects[0]
        bpy.ops.export_scene.gltf(filepath=str(EXPORT/"appearance_c.glb"),export_format="GLB",use_selection=True,export_yup=True)
        bpy.ops.object.select_all(action="DESELECT")
        (EXPORT/"evaluated_mesh_manifest.json").write_text(json.dumps({"scene_sha256":sha(args.scene),"bevels_applied":True,"parts":evaluated},indent=2)+"\n")
    bpy.ops.mesh.primitive_plane_add(size=200,location=(0,0,-.004))
    floor=bpy.context.object;floor.name="studio_shadow_floor";floor.is_shadow_catcher=True
    floor_mat=bpy.data.materials.new("studio_floor");floor_mat.diffuse_color=(.95,.95,.95,1);floor.data.materials.append(floor_mat)
    def light(name,pos,power,size):
        ld=bpy.data.lights.new(name,"AREA");ld.energy=power;ld.shape="DISK";ld.size=size
        ob=bpy.data.objects.new(name,ld);bpy.context.collection.objects.link(ob);ob.location=pos
        ob.rotation_euler=(Vector((0,0,1.4))-ob.location).to_track_quat("-Z","Y").to_euler()
    light("key_front",(4,-3,6),250,4);light("fill_left",(1,4,4),180,4);light("rear_soft",(-4,1,5),250,4)
    cam=bpy.data.cameras.new("source_orthographic_camera");ob=bpy.data.objects.new("source_orthographic_camera",cam)
    bpy.context.collection.objects.link(ob);scene.camera=ob;cam.type="ORTHO"
    positions={"front":((8,0,1.325),(0,0,1.325),3.04),"left":((0,8,1.325),(0,0,1.325),3.04),
               "rear":((-8,0,1.325),(0,0,1.325),3.04),"top":((0,0,8),(.1,0,0),2.26),
               "structure_front":((8,0,1.325),(0,0,1.325),3.04),
               "structure_left":((0,8,1.325),(0,0,1.325),3.04),
               "structure_threequarter":((4,-6,3.7),(0,0,1.325),3.10),
               "threequarter":((4,-6,3.7),(0,0,1.325),3.10),
               "chest_detail":((6,-1,2.5),(.12,0,2.22),1.38),
               "rear_panel_detail":((-6,-.8,2.3),(-.44,0,2.19),.64),
               "hand_detail":((5,3,2),(.13,.84,1.04),.63),
               "leg_detail":((5,3,1.4),(.1,.44,.69),1.31),
               "foot_left":((0,8,.22),(.025,.50,.18),1.03),
               "foot_folded_left":((0,8,.22),(.025,.50,.18),1.03),
               "foot_mechanism_left":((1.2,3.7,.80),(.025,.50,.18),1.03),
               "top_reference":((2.80,0,4.50),(.1,0,1.50),2.55),
               "front_reference":((8,0,2.20),(0,0,1.325),3.04),
               "top_pose_a":((.362,0,4.50),(.1,0,1.50),2.55),
               "top_near_vertical":((.1,0,5.0),(.1,0,1.45),2.55),
               "top_upper_assembly":((2.80,0,4.50),(.1,0,1.82),2.40)}
    ob.location=(4,-6,3.7);ob.rotation_euler=(Vector((0,0,1.325))-ob.location).to_track_quat("-Z","Y").to_euler();cam.ortho_scale=3.1
    if not args.no_export:bpy.ops.wm.save_as_mainfile(filepath=str(ROBOT/"cad/source/appearance_c.blend"))
    camera_records=[]
    for name in args.views.split(","):
        pos,target,scale=positions[name];ob.location=pos
        ob.rotation_euler=(Vector(target)-ob.location).to_track_quat("-Z","Y").to_euler()
        cam.type="ORTHO";cam.ortho_scale=scale
        if name=="top":ob.rotation_euler=(0,0,math.pi/2)
        if name in ("top_reference","top_near_vertical","top_upper_assembly","top_pose_a"):
            cam.type="PERSP";cam.lens=58 if name=="top_near_vertical" else 45;cam.sensor_width=36
            if name=="top_near_vertical":ob.rotation_euler=(0,0,math.pi/2)
        hidden=[]
        pose=None
        if name=="foot_folded_left":
            affected=[];unlocks=[]
            for mesh in objects:
                part=foot_parts.get(mesh.name)
                if part is None or not mesh.name.startswith("left_"):
                    mesh.hide_render=True;hidden.append(mesh.name);continue
                group=part["composite_foot_group"]
                if group in ("forefoot","heel"):
                    pivot=Vector(part["composite_foot_pivot_world_m"])
                    angle=-15 if group=="forefoot" else 10
                    mesh.matrix_world=Matrix.Translation(pivot)@Matrix.Rotation(math.radians(angle),4,"Y")@Matrix.Translation(-pivot)
                    affected.append(mesh.name)
                elif group=="lock":
                    delta=part.get("composite_foot_unlock_translation_world_m")
                    if delta is None:raise ValueError("Fold probe lacks lock withdrawal: "+mesh.name)
                    mesh.matrix_world=Matrix.Translation(Vector(delta));unlocks.append({"mesh":mesh.name,"translation_world_m":delta})
            floor.hide_render=True
            pose={"scope":"Isolated unloaded foot mechanism probe; no ground support, gait or validated angular limits.",
                  "forefoot_deg":-15,"heel_deg":10,"axis_world":[0,1,0],"affected_mesh_names":affected,"lock_withdrawals":unlocks,
                  "interpretation":"Real segment-owned mesh rotations and lock withdrawal. All non-foot geometry and studio floor explicitly hidden; not whole-robot clearance evidence."}
        if name=="foot_mechanism_left":
            for mesh in objects:
                part=foot_parts.get(mesh.name)
                mechanism=part is not None and part["role"] in (
                    "visible_mechanism","primary_structure_candidate","primary_structure_socket_candidate")
                if part is None or not mesh.name.startswith("left_") or not mechanism:
                    mesh.hide_render=True;hidden.append(mesh.name)
        if name=="top_pose_a":
            spec=json.loads((ROOT/data["spec_path"]).read_text());affected=[]
            # Candidate display pose only: each complete arm stays rigidly
            # connected at its existing shoulder. No foot translation/hiding.
            for side in ("left","right"):
                pivot=Vector(spec["points_world_m"][side+"_shoulder"])
                transform=Matrix.Translation(pivot)@Matrix.Rotation(math.radians(-50),4,"Y")@Matrix.Translation(-pivot)
                for mesh in objects:
                    body=mesh["body"]
                    if body.startswith(side+"_") and any(label in body for label in ("upper_arm","forearm","palm","finger","thumb")):
                        mesh.matrix_world=transform;affected.append(mesh.name)
            pose={"scope":"Illustrative shoulder display pose, not a physical joint contract or validated feasible posture.",
                  "axis_world":[0,1,0],"rotation_deg":-50,"description":"Both complete arms forward about the source shoulder pivots; all legs and feet remain neutral.",
                  "affected_mesh_names":affected}
        if name=="top_upper_assembly":
            for mesh in objects:
                body=mesh["body"]
                if any(label in body for label in ("thigh","middle_shank","distal_shank","foot","hip_","knee_","ankle_")):
                    mesh.hide_render=True;hidden.append(mesh.name)
        if name.startswith("structure_"):
            for mesh in objects:
                if not mesh["structure_view_visible"]:
                    mesh.hide_render=True;hidden.append(mesh.name)
        camera_records.append({"view":name,"projection":cam.type,"position_m":list(pos),"target_m":list(target),
            "rotation_euler_rad":list(ob.rotation_euler),"ortho_scale_m":scale if cam.type=="ORTHO" else None,
            "lens_mm":cam.lens if cam.type=="PERSP" else None,"sensor_width_mm":cam.sensor_width if cam.type=="PERSP" else None,
            "assembly_isolation":name in ("top_upper_assembly","foot_folded_left","foot_mechanism_left") or name.startswith("structure_"),"hidden_mesh_names":hidden,
            "display_pose":pose,
            "interpretation":"Isolated unloaded composite-foot probe; hidden objects and lock withdrawal recorded, no supported-body motion claim." if name=="foot_folded_left" else "Foot mechanism isolation; hidden covers recorded, no strength claim." if name=="foot_mechanism_left" else "Actual primary member and joint-seat isolation; hidden covers recorded. Not whole appearance or strength acceptance." if name.startswith("structure_") else "Uncalibrated artwork camera/pose candidate; not appearance acceptance." if name.startswith("top_") or name.endswith("_reference") else "Actual neutral geometry."})
        scene.render.filepath=str(IMAGES/f"{args.tag}_{name}.png")
        bpy.ops.render.render(write_still=True)
        for mesh in objects:mesh.hide_render=False;mesh.matrix_world=Matrix.Identity(4)
        floor.hide_render=False
    (EXPORT/f"{args.tag}_camera_manifest.json").write_text(json.dumps(camera_records,indent=2)+"\n")

if __name__=="__main__":
    args=arguments()
    try:import bpy
    except ImportError:wrapper(args)
    else:blender_render(args)

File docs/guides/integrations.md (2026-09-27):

# Game integrations

## Robot family update

The core repository is now [Sai_Rotbots](https://github.com/sgyli7/Sai_Rotbots).
001 remains the default. With the new family package, select
`uv run sai-agent godot --robot Sai_Agent_002` or add `--task cargo`.
The existing external Godot and Unity source pins still identify 001 alpha.3;
renaming preserves their old GitHub URLs through redirects. Do not infer 002
support in an old integration checkout merely from the repository rename.
The 002 bundle provides its own MJCF, JSON physical specification and Y-up GLBs.

The model is shared as a version-pinned Python package containing the original
MJCF articulation, public display/contact assets and policy weights. Neither
integration replaces the existing MicroDuck default.

## Godot

In [MicroDuck-Godot-Simi2Sim](https://github.com/sgyli7/MicroDuck-Godot-Simi2Sim):

```sh
uv sync --extra sai
uv run --extra sai sim2sim-play --robot Sai_Agent_001
```

Use Python 3.12 and Godot 4.7.2. The optional dependency pins an exact Sai source
commit; inspect that project's `pyproject.toml` for the currently selected
version. The launcher imports GLBs and starts the local policy service itself.
It supports the dedicated Sai scene; MicroDuck forest presets are not yet a
drop-in terrain conversion for this robot.

The initial integration was checked by a fresh remote package install, actual
Godot W key input and all 38 existing MD input tests. Dedicated Sai acceptance
also covers S/A/D/Shift, continuous 20/40 mm stairs and the cargo task. Those are
separate tests, not claims that every MD scene or user PC has been verified.

## Unity / Tuanjie

[Integration PR #3](https://github.com/sgyli7/MicroDuck-Unity-Sim2Sim/pull/3)
contains `scripts/setup-sai-agent.py`, the native-model controller, display
import and the `SaiAgent001/Build Demo` editor menu.
Until the draft PR is merged, use its preview branch in a separate checkout:

```sh
git clone --branch feat/sai-agent-001 --single-branch https://github.com/sgyli7/MicroDuck-Unity-Sim2Sim.git Sai-Unity-preview
cd Sai-Unity-preview
python scripts/setup-sai-agent.py
```

Then open the existing Tuanjie project, run **SaiAgent001 → Build Demo**, and
enter Play mode. The adapter uses the original articulated native MuJoCo model
directly and the exported ONNX actor. W/S drive, A/D turn, held Shift crouches,
and R resets the native model. The display wrapper uses the blue shell and
SO101 meshes while preserving all collision and inertial data.

**SaiAgent001 → Build Stairs** creates separate four-riser 20/40 mm ascent and
descent scenes. The controller uses 24 terrain-only rays, both frozen actors
and the same bounded heading control as the Godot adapter.

The setup script fetched and installed the pinned GitHub assets. The C# control
contract passed 64 flat plus 160 stair/heading Python fixtures under .NET 8;
maximum absolute difference is below 4.2e-7. The expanded suite now covers
384 total formula cases. More importantly, the actual shared
`SaiNativeWorld` source passes eight movement/crouch/reset cases and four stair
cases with MuJoCo 3.12.0 and ONNX Runtime 1.24.4. These passed on Linux ARM64 and
in [Linux/Windows CI](https://github.com/sgyli7/MicroDuck-Unity-Sim2Sim/actions/runs/34680834372).
The Windows run loads the actual project-bundled DLL with its locked SHA-256.
The tests advance real native physics, not prescribed robot poses. The same
C# source now also passes nominal 60 mm up/down locally, using the separately
paired ascent60/descent60 settings. The editor menu exposes those under
**Build Experimental Stairs**. The compact
record is [unity-native-physics.json](../../robots/Sai_Agent_001/evidence/unity-native-physics.json).

**Unity/Tuanjie editor execution has not been tested on this Linux ARM workstation,
which has no supported editor installed.** The PR remains a draft. A real editor
entry point is now prepared:

```sh
python scripts/run-sai-editor-acceptance.py --editor "/absolute/path/to/editor"
```

Add `--build-windows` on a host with the Windows build module to run that
acceptance first and then build the player. The helper checks a fresh completion
marker, executable and locked native DLL, and writes a file/hash manifest.
This preparation passed Linux/Windows CI at integration commit `f38bd3c`;
the editor build and player execution themselves have not run here.

It imports the real ONNX assets and runs the same physical acceptance suite via
the gameplay Barracuda wrapper, writing an explicit editor report. It has not
yet been executed here. Keyboard input and rendering additionally need Play
acceptance. Cargo pickup/transport has not yet been ported to this Unity demo;
the working Godot task does not establish Unity task support.

## Physics and sensing

Godot/Jolt advances its own rigid bodies; Python uses MuJoCo only for FK and
gravity bias. Unity's adapter advances native MuJoCo and only synchronizes
display transforms. No engine drives the robot by setting the chassis pose.
The terrain observations are simulation height queries/rays. Camera images are
rendered but are not the source of those heights or a trained VLA policy.

Alpha.3 is [released](https://github.com/sgyli7/Sai_Agent_001/releases/tag/v0.1.0-alpha.3).
Godot [PR #4](https://github.com/sgyli7/MicroDuck-Godot-Simi2Sim/pull/4) is merged
with the new exact source pin. Unity's twelve base plus two experimental cases
also pass [Linux/Windows CI](https://github.com/sgyli7/MicroDuck-Unity-Sim2Sim/actions/runs/34685536330).
Editor acceptance remains pending; the repeated lack of an editor host cannot
be resolved by more native-console tests.

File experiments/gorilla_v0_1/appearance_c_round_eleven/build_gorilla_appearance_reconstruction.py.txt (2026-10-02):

#!/usr/bin/env python3
"""Reconstruct the sole Gorilla AA3 artwork as editable hard-surface geometry.

This appearance source has no physical approval or inferred hardware mass.
Pixel coordinates refer to the user's original 1280-square sheet; hidden depths
are explicit reconstruction choices, not measurements from calibrated cameras.
"""
from __future__ import annotations

import argparse
import hashlib
import json
import math
from pathlib import Path

import numpy as np
from scipy.interpolate import PchipInterpolator

from build_gorilla_proportion_layout import Geometry as PrimitiveGeometry

ROOT = Path(__file__).resolve().parents[2]
ROBOT = ROOT / "robots/gorilla_v0_1"
SCALE = 2.65 / 516
CX = 325.5
GROUND = 603
PALETTE = {
    "ivory": [0.91, 0.88, 0.80, 1],
    "blue": [0.015, 0.57, 0.88, 1],
    "gold": [1.0, 0.64, 0.13, 1],
    "dark": [0.075, 0.08, 0.084, 1],
    "metal": [0.16, 0.17, 0.17, 1],
    "black": [0.018, 0.022, 0.026, 1],
}
IVORY, BLUE, GOLD, DARK, METAL, BLACK = (PALETTE[k] for k in ("ivory", "blue", "gold", "dark", "metal", "black"))

def sha(path: Path) -> str:
    return hashlib.sha256(path.read_bytes()).hexdigest()

def yz(px, py, rear=False):
    return np.array([(px - CX if rear else CX - px) * SCALE, (GROUND - py) * SCALE])

class Geometry(PrimitiveGeometry):
    """A named control mesh plus explicit surface finish parameters."""

    def part(self, name, body, vertices, faces, color, hardware=False, note=""):
        super().part(name, body, vertices, faces, color, hardware, note)
        part = self.parts[-1]
        part.pop("shell_density_kg_m3")
        part.pop("shell_thickness_m")
        part.pop("mass_basis_note")
        part.update({
            "role": "visible_mechanism" if hardware else "armor_surface",
            "physical_mass_assigned": False,
            "reconstruction_note": note or "Visible shape reconstructed from the sole artwork; hidden depth is a candidate.",
            "edge_bevel_m": 0,
            "bevel_segments": 3,
            "surface_shading": "mechanical_smooth" if hardware else "flat_weighted_normals",
        })

    def cover(self,name,body,vertices,surface_faces,color,thickness=.007,
              reference_closed_faces=None,sharp_outer_edges=None,note=""):
        """A hollow armor cover: outer skin, inner skin and boundary returns.

        Openings remain openings. Only the thin material is a closed volume;
        the assembly cavity is never filled by a colored solid. Thickness is
        an editable appearance construction parameter, not a strength result.
        """
        source=np.asarray(vertices,float)
        faces=[list(f) for f in surface_faces]
        if reference_closed_faces:
            volume=sum(np.dot(source[f[0]],np.cross(source[f[i]],source[f[i+1]]))/6
                for f in reference_closed_faces for i in range(1,len(f)-1))
            if volume<0:faces=[list(reversed(f)) for f in faces]
        used=sorted({v for f in faces for v in f});mapping={v:i for i,v in enumerate(used)}
        outside=source[used];faces=[[mapping[v] for v in f] for f in faces]
        normals=np.zeros_like(outside)
        for f in faces:
            area=sum((np.cross(outside[f[i]]-outside[f[0]],outside[f[i+1]]-outside[f[0]])
                for i in range(1,len(f)-1)),start=np.zeros(3))
            for v in f:normals[v]+=area
        lengths=np.linalg.norm(normals,axis=1)
        if np.any(lengths<1e-12):raise ValueError("Undefined armor surface normal: "+name)
        normals/=lengths[:,None]
        t=np.full(len(outside),thickness) if np.isscalar(thickness) else np.asarray(thickness)[used]
        inside=outside-normals*t[:,None];n=len(outside)
        edge_counts={};directions={}
        for f in faces:
            for a,b in zip(f,f[1:]+f[:1]):
                key=tuple(sorted((a,b)));edge_counts[key]=edge_counts.get(key,0)+1;directions[key]=(a,b)
        if any(v>2 for v in edge_counts.values()):raise ValueError("Branching armor surface: "+name)
        boundary=[directions[k] for k,count in edge_counts.items() if count==1]
        material_faces=faces+[[n+i for i in reversed(f)] for f in faces]
        material_faces += [[b,a,a+n,b+n] for a,b in boundary]
        self.part(name,body,np.concatenate((outside,inside)),material_faces,color,note=note)
        sharp=[]
        for a,b in sharp_outer_edges or []:
            if a in mapping and b in mapping:
                a,b=mapping[a],mapping[b];sharp.extend([[a,b],[a+n,b+n]])
        sharp.extend([[a,b] for a,b in boundary]);sharp.extend([[a+n,b+n] for a,b in boundary])
        self.parts[-1].update({"role":"armor_cover","surface_shading":"curved_hard_surface",
            "edge_bevel_m":0,"auto_smooth_angle_deg":180,
            "sharp_surface_edge_pairs":sharp,"cover_construction":"outer_skin_inner_skin_boundary_returns_open_cavity",
            "appearance_skin_thickness_range_m":[float(t.min()),float(t.max())],
            "skin_thickness_is_manufacturing_spec":False,"open_boundary_edge_count":len(boundary),
            "reconstruction_note":note or "Thin armor cover around an open assembly cavity; hidden return/thickness remain appearance candidates, not load-bearing evidence."})

    def panel(self, name, body, outline, front, depth, color, bevel=.006, rear=False, camber=.012):
        """A shaped plate from an artwork outline, with separately editable rim.

        outline uses original full-sheet FRONT pixels. rear=True reverses lateral
        coordinates and extrusion. Front can be a scalar or f(y,z) surface depth.
        The source is genuine three-dimensional geometry, with no image texture.
        """
        q = np.array([yz(x, z, rear) for x, z in outline])
        center = q.mean(axis=0)
        inward = center + .94 * (q - center)
        sign = -1 if rear else 1
        def position(p, inset=0):
            y, z = p
            x = front(y, z) if callable(front) else front
            return [x + sign * inset, y, z]
        v = [position(p) for p in q]
        v += [position(p, camber) for p in inward]
        v += [position(p, -depth) for p in q]
        n = len(q)
        v.append(position(center, camber))
        faces = []
        for i in range(n):
            j = (i + 1) % n
            faces.extend([[i, j, n+j, n+i], [n+i, n+j, 3*n], [i, 2*n+i, 2*n+j, j]])
        faces.append(list(reversed(range(2*n, 3*n))))
        self.part(name, body, v, faces, color)
        self.parts[-1]["edge_bevel_m"] = bevel
        self.parts[-1]["reference_outline_px"] = outline

    def tube(self, name, body, points, radius, color, n=10):
        # Closed constant-section polylines for seams, conduits and trim.
        for i, (a, b) in enumerate(zip(points[:-1], points[1:])):
            self.link(f"{name}_{i:02}", body, a, b, [(0, radius, radius), (1, radius, radius)], color, True, n)
            self.parts[-1]["edge_bevel_m"] = 0

    def seam(self, name, body, pixels, surface, radius=.0013, color=METAL, rear=False):
        line=[]
        for px, py in pixels:
            y,z=yz(px,py,rear)
            x=surface(y,z) if callable(surface) else surface
            line.append([x+(-.003 if rear else .003),y,z])
        self.tube(name,body,line,radius,color,8)

    def bolt(self, name, body, pos, axis=(1,0,0), radius=.006, color=METAL):
        a=np.asarray(pos,float);d=np.asarray(axis,float);d/=np.linalg.norm(d)
        self.link(name,body,a-d*.002,a+d*.002,[(0,radius,radius),(1,radius,radius)],color,True,12)
        self.parts[-1]["edge_bevel_m"] = .0006

    def rounded_rect(self, name, body, center, width, height, thickness, radius, color, rear=False):
        # The rectangle's broad face is in YZ, with actual rounded corners.
        cx,cy,cz=center
        p=[]
        for sy,sz,start in ((1,1,0),(-1,1,90),(-1,-1,180),(1,-1,270)):
            # Profile generated clockwise in YZ.
            yc=cy+sy*(width/2-radius);zc=cz+sz*(height/2-radius)
            for a in np.linspace(start,start+90,7):
                t=math.radians(a)
                p.append([yc+radius*math.cos(t),zc+radius*math.sin(t)])
        n=len(p);sgn=-1 if rear else 1
        v=[[cx,y,z] for y,z in p]+[[cx-sgn*thickness,y,z] for y,z in p]
        f=[list(reversed(range(n))),list(range(n,2*n))]
        f += [[i,(i+1)%n,(i+1)%n+n,i+n] for i in range(n)]
        self.part(name,body,v,f,color,True)
        self.parts[-1]["edge_bevel_m"] = .0015

CHEST_CURVE=PchipInterpolator(
    (GROUND-np.array([274,271,248,218,184,162,136,120,106,96,87,85]))*SCALE,
    (971-np.array([918,907,888,871,861,855,876,891,918,949,986,1010]))*SCALE)
CHEST_BACK_CURVE=PchipInterpolator(
    (GROUND-np.array([259,254,232,202,165,135,111,93,85]))*SCALE,
    (971-np.array([1028,1036,1048,1055,1058,1057,1041,1025,1010]))*SCALE)

def chest_front(y,z):
    x=float(CHEST_CURVE(z))
    return x-.020*(abs(y)/.37)**2

def chest_back(y,z):
    return float(CHEST_BACK_CURVE(z))+.018*(abs(y)/.4)**2

def mirror_outline(outline):
    return [[2*CX-x,y] for x,y in reversed(outline)]

def polygon_span(outline, scan_y):
    crossings=[]
    for a,b in zip(outline,outline[1:]+outline[:1]):
        if abs(a[1]-b[1])<1e-9:
            if abs(scan_y-a[1])<1e-8:crossings.extend([a[0],b[0]])
        elif min(a[1],b[1])-1e-8<=scan_y<=max(a[1],b[1])+1e-8:
            crossings.append(a[0]+(b[0]-a[0])*(scan_y-a[1])/(b[1]-a[1]))
    if not crossings:raise ValueError(f"No contour at {scan_y}")
    return min(crossings),max(crossings)

def triangulate_outline(points):
    """Ear clipping retains the original yellow guard's bottom notch."""
    q=np.asarray(points,float);remaining=list(range(len(q)));triangles=[]
    orient=np.sign(sum(q[i,0]*q[(i+1)%len(q),1]-q[(i+1)%len(q),0]*q[i,1] for i in range(len(q))))
    while len(remaining)>3:
        for k,i in enumerate(remaining):
            a,b=remaining[k-1],remaining[(k+1)%len(remaining)]
            u,v=q[i]-q[a],q[b]-q[i]
            if orient*(u[0]*v[1]-u[1]*v[0])<=1e-12:continue
            mat=np.column_stack((q[i]-q[a],q[b]-q[a]));blocked=False
            for j in remaining:
                if j in (a,i,b):continue
                uv=np.linalg.solve(mat,q[j]-q[a])
                if min(uv[0],uv[1],1-uv.sum())>=-1e-9:blocked=True;break
            if not blocked:
                triangles.append([a,i,b]);remaining.pop(k);break
        else:raise ValueError("Cannot triangulate reference outline")
    triangles.append(remaining);return triangles

def fitted_guard(g,name,body,outline,front,back,color,rear=False,outer_bevel=.007,inset_height=.005,inset_ratio=.90,open_cover=False):
    """A genuinely three-dimensional guard, preserving a concave rim."""
    q=np.asarray([yz(x,z,rear) for x,z in outline]);center=q.mean(0)
    inset=center+inset_ratio*(q-center);sgn=-1 if rear else 1;n=len(q)
    parameters=[[y,z,1.,-sgn*outer_bevel] for y,z in q]
    parameters += [[y,z,1.,sgn*inset_height] for y,z in inset]
    parameters += [[y,z,0.,0.] for y,z in q]
    faces=[]
    for i in range(n):
        j=(i+1)%n
        faces.extend([[i,j,n+j,n+i],[i,2*n+i,2*n+j,j]])
    faces += [[n+i for i in t] for t in triangulate_outline(inset)]
    faces += [list(reversed([2*n+i for i in t])) for t in triangulate_outline(q)]
    faces=[[f[0],f[i],f[i+1]] for f in faces for i in range(1,len(f)-1)]
    # Refinement happens in the common YZ/layer parameterization before the
    # depth functions are evaluated. Large ear triangles on a curved surface
    # otherwise make star-shaped facets and differ under mirrored diagonals.
    for _ in range(3):
        midpoints={};refined=[]
        def midpoint(a,b):
            edge=tuple(sorted((a,b)))
            if edge not in midpoints:
                midpoints[edge]=len(parameters)
                parameters.append(((np.asarray(parameters[a])+np.asarray(parameters[b]))/2).tolist())
            return midpoints[edge]
        for a,b,c in faces:
            ab,bc,ca=midpoint(a,b),midpoint(b,c),midpoint(c,a)
            refined.extend([[a,ab,ca],[ab,b,bc],[ca,bc,c],[ab,bc,ca]])
        faces=refined
    vertices=[]
    for y,z,blend,offset in parameters:
        vertices.append([(1-blend)*back(y,z)+blend*front(y,z)+offset,y,z])
    if open_cover:
        outside=[f for f in faces if not all(parameters[v][2]<1e-8 for v in f)]
        g.cover(name,body,vertices,outside,color,.006,faces)
    else:g.part(name,body,vertices,faces,color)
    g.parts[-1].update({"edge_bevel_m":0,"surface_shading":"curved_hard_surface","reference_outline_px":outline,
        "reconstruction_note":"Observed visible region retained as a closed candidate surface with native rim; curved depth and hidden closure are separately inferred."})

def fitted_radiator(g,side,sign,profiles):
    """Original front contour and chamfered side support, not a white box."""
    side_mount=profiles["left"]["side_vent_ivory_mount"]
    def surface(y,z,rear=False):
        py=np.clip(GROUND-z/SCALE,161.15,222.85)
        a,b=polygon_span(side_mount,float(py))
        return (971-(b if rear else a))*SCALE+(.008 if rear else -.009)
    def outline(key):
        q=profiles["front"][key]
        return q if sign==1 else mirror_outline(q)
    fitted_guard(g,side+"_radiator_ivory_socket","torso",outline("left_vent_ivory_mount"),
        surface,lambda y,z:surface(y,z,True),IVORY)
    g.parts[-1]["reconstruction_note"]="Ivory support fits original FRONT outline and visible LEFT support contour; gold bezel remains recessed within this support."
    fitted_guard(g,side+"_radiator_gold_trim","torso",outline("left_vent_gold_bezel"),
        lambda y,z:surface(y,z)+.013,lambda y,z:surface(y,z)+.005,GOLD,
        outer_bevel=.002,inset_height=.0015,inset_ratio=.93)
    fitted_guard(g,side+"_radiator_black_well","torso",outline("left_vent_black_opening"),
        lambda y,z:surface(y,z)+.018,lambda y,z:surface(y,z)+.010,BLACK,
        outer_bevel=.001,inset_height=.0005,inset_ratio=.95)
    for i,py in enumerate(np.linspace(167.2,202.3,11)):
        a,b=polygon_span(profiles["front"]["left_vent_black_opening"],float(py))
        y=sign*(CX-(a+b)/2)*SCALE;z=(GROUND-py)*SCALE
        g.box(side+f"_radiator_louver_{i:02}","torso",[surface(y,z)+.024,y,z],
            [.005,(b-a-2.4)*SCALE,.0038],[.29,.29,.25,1],True)
        g.parts[-1]["edge_bevel_m"] = .0008
    for i,(px,py) in enumerate(((253,165),(271,167),(254,204),(269,203))):
        y=sign*(CX-px)*SCALE;z=(GROUND-py)*SCALE
        g.bolt(side+f"_vent_fastener_{i}","torso",[surface(y,z)+.023,y,z],radius=.003)

def edge_u_at_v(edge, py):
    """Read a sampled artwork crease; endpoint continuation is an inference."""
    ordered=sorted(edge,key=lambda p:p[1])
    return float(np.interp(py,[p[1] for p in ordered],[p[0] for p in ordered]))

def dual_view_shell(g,name,body,front_outline,side_outline,color,sign=1,steps=15,
                    front_feature_edges=None,facet_mode=None):
    """A wraparound shell constrained by front and left silhouettes.

    The cross section has broad planes with curved/chamfered transitions. This
    changes the geometry type, rather than thickening a two-dimensional plate.
    Side art is uncalibrated and therefore remains an appearance depth choice.
    """
    # FRONT determines visible height. Intersecting two uncalibrated view
    # ranges previously cut off shoulder/arm overlap and the shank's top.
    lower=min(p[1] for p in front_outline)+.15
    upper=max(p[1] for p in front_outline)-.15
    side_lo=min(p[1] for p in side_outline)+.15
    side_hi=max(p[1] for p in side_outline)-.15
    profile=[(1,-.58),(1,.58),(.82,.87),(.50,1),(-.54,1),(-.91,.77),(-1,.35),
             (-1,-.35),(-.91,-.77),(-.54,-1),(.50,-1),(.82,-.87)]
    vertices=[]
    samples=sorted(set([*np.linspace(lower,upper,steps),
        *[p[1] for p in front_outline if lower<p[1]<upper]]))
    for py in samples:
        fa,fb=polygon_span(front_outline,float(py))
        sa,sb=polygon_span(side_outline,float(np.clip(py,side_lo,side_hi)))
        y0,y1=(CX-fb)*SCALE,(CX-fa)*SCALE
        x0,x1=(971-sb)*SCALE,(971-sa)*SCALE
        cy,ry=(y0+y1)/2,max((y1-y0)/2,.003)
        cx,rx=(x0+x1)/2,max((x1-x0)/2,.004)
        if facet_mode:
            width=fb-fa
            if facet_mode in ("forearm","thigh"):
                first,second=(edge_u_at_v(e,py) for e in front_feature_edges)
            elif facet_mode=="middle_shank":
                first=fa+.14*width;second=edge_u_at_v(front_feature_edges[0],py)
            else:
                first=fa+.14*width;second=edge_u_at_v(front_feature_edges[0],py)
            # Creases may continue into occluded/narrow terminal regions. Keep
            # them ordered within the observed outline without zero-area rims.
            first=float(np.clip(first,fa+.12*width,fb-.35*width))
            second=float(np.clip(second,first+.18*width,fb-.12*width))
            ya=(CX-first)*SCALE;yb=(CX-second)*SCALE
            band=min(.012,.035*(y1-y0))
            xf,xr=x1,x0;depth=max(xf-xr,.008)
            front_drop=min(.018,.065*depth)
            ring=[(xf-.30*depth,y1),(xf-front_drop,ya+band),(xf,ya),
                  (xf-.007*min(1,depth/.16),yb),
                  (xf-front_drop-.007*min(1,depth/.16),yb-band),
                  (xf-.31*depth,y0),(xf-.62*depth,y0),
                  (xr+.12*depth,y0+.10*(y1-y0)),(xr,y0+.32*(y1-y0)),
                  (xr,y1-.32*(y1-y0)),(xr+.12*depth,y1-.10*(y1-y0)),
                  (xf-.62*depth,y1)]
            vertices.extend([[x,sign*y,(GROUND-py)*SCALE] for x,y in ring])
        else:
            for xx,yy in profile:vertices.append([cx+rx*xx,sign*(cy+ry*yy),(GROUND-py)*SCALE])
    n=len(profile);steps=len(samples);faces=[list(reversed(range(n)))]
    for k in range(steps-1):
        for i in range(n):
            j=(i+1)%n;faces.append([k*n+i,k*n+j,(k+1)*n+j,(k+1)*n+i])
    faces.append(list(range((steps-1)*n,steps*n)))
    if facet_mode=="deltoid":sector=[0,1,2,3,4,10,11]
    elif "ivory" in name:sector=[0,1,2,3,9,10,11]
    elif facet_mode=="middle_shank":sector=[0,1,2,3,4,5,10,11]
    else:sector=list(range(n))
    outer=[f for k in range(steps-1) for i in sector
        for f in [[k*n+i,k*n+(i+1)%n,(k+1)*n+(i+1)%n,(k+1)*n+i]]]
    sharp_rings=[1,2,3,4,6,8,9,11] if facet_mode else []
    sharp_edges=[[k*n+i,(k+1)*n+i] for k in range(steps-1) for i in sharp_rings]
    thickness=[]
    for k in range(steps):
        ring=np.asarray(vertices[k*n:(k+1)*n]);span=ring.ptp(axis=0) if hasattr(ring,"ptp") else np.ptp(ring,axis=0)
        wall=max(.0007,min(.007,.20*min(span[:2])))
        thickness.extend([wall]*n)
    g.cover(name,body,vertices,outer,color,thickness,faces,sharp_edges)
    g.parts[-1].update({"edge_bevel_m":0,"surface_shading":"curved_hard_surface",
        "auto_smooth_angle_deg":180 if facet_mode else 50,
        "ring_vertex_count":n,
        "reference_front_outline_px":front_outline,"reference_left_outline_px":side_outline,
        "reference_front_feature_edges_px":front_feature_edges or [],
        "front_facet_mode":facet_mode,
        "front_height_preserved":True,"left_depth_endpoint_continuation":"clamped, unobserved where outside LEFT outline height",
        "reconstruction_note":"Full FRONT contour retained with part-specific broad face bands. This is a thin open armor cover around mechanisms, not a filled colored volume. LEFT depth/hidden returns are uncalibrated candidates."})

def shoulder_sweep(g,side,sign,profiles):
    # The front end narrows inward and down, rather than project as a flat
    # rectangular shoulder pad. Sections wrap the same underlying dark socket.
    sections=[
        [[.335,.235,2.335],[.145,.457,2.445],[.112,.470,2.400],[.308,.260,2.310]],
        [[.160,.302,2.477],[.083,.548,2.458],[.066,.557,2.411],[.137,.320,2.430]],
        [[.035,.345,2.549],[-.020,.586,2.538],[-.022,.593,2.491],[.015,.359,2.501]],
        [[-.105,.370,2.572],[-.105,.578,2.553],[-.105,.584,2.505],[-.105,.382,2.523]],
        [[-.228,.373,2.543],[-.232,.553,2.516],[-.213,.560,2.472],[-.206,.382,2.495]],
        [[-.322,.330,2.458],[-.308,.540,2.447],[-.275,.546,2.411],[-.288,.345,2.415]],
        [[-.290,.273,2.344],[-.300,.491,2.420],[-.265,.506,2.394],[-.263,.285,2.318]],
    ]
    reference=profiles["front"]["left_blue_shoulder_sweep"]
    for section in sections:
        for p in section:
            py=np.clip(GROUND-p[2]/SCALE,101.15,154.85)
            a,b=polygon_span(reference,float(py))
            p[1]=float(np.clip(p[1],(CX-b)*SCALE,(CX-a)*SCALE))
    vertices=[[x,sign*y,z] for section in sections for x,y,z in section]
    faces=[[3,2,1,0]]
    for k in range(len(sections)-1):
        for i in range(4):faces.append([4*k+i,4*k+(i+1)%4,4*(k+1)+(i+1)%4,4*(k+1)+i])
    faces.append(list(range(4*(len(sections)-1),4*len(sections))))
    surface=[[4*k+i,4*k+(i+1)%4,4*(k+1)+(i+1)%4,4*(k+1)+i]
        for k in range(len(sections)-1) for i in (0,1,3)]
    g.cover(side+"_blue_continuous_shoulder_sweep","torso",vertices,surface,BLUE,.006,faces)
    g.parts[-1].update({"edge_bevel_m":0,"surface_shading":"curved_hard_surface",
        "reconstruction_note":"Open saddle cover over the dark shoulder bearing, with thin skin and lip returns; FRONT span constrained by the original diagonal shoulder band, not a filled shoulder pad."})
    # The front diagonal wing is its own shallow cover over the saddle end.
    patch_cover(g,side+"_blue_shoulder_diagonal_front_wing","torso",reference,sign,
        lambda y,z:float(np.interp(GROUND-z/SCALE,[101,109,121,128,144,155],[-.10,.02,.135,.20,.325,.295])),BLUE,.006)

def patch_cover(g,name,body,outline,sign,surface,color,skin=.007):
    samples=sorted(set([*np.linspace(min(p[1] for p in outline)+.12,max(p[1] for p in outline)-.12,28),
        *[p[1] for p in outline][1:-1]]))
    samples=[v for v in samples if min(p[1] for p in outline)+.1<=v<=max(p[1] for p in outline)-.1]
    across=[0,.045,.20,.50,.80,.955,1.];vertices=[]
    for py in samples:
        a,b=polygon_span(outline,float(py));z=(GROUND-py)*SCALE
        for t in across:
            y=sign*(CX-(a+t*(b-a)))*SCALE
            vertices.append([surface(y,z)+.003*math.sin(math.pi*t),y,z])
    n=len(across);faces=[]
    for k in range(len(samples)-1):
        for i in range(n-1):faces.append([k*n+i,k*n+i+1,(k+1)*n+i+1,(k+1)*n+i])
    # FRONT order above points outward +X (mirroring reverses this winding).
    if sign<0:faces=[list(reversed(f)) for f in faces]
    g.cover(name,body,vertices,faces,color,skin)
    g.parts[-1].update({"reference_front_outline_px":outline,
        "reconstruction_note":"A separate thin broad armor panel with actual open back and boundary return; FRONT profile is observed, surface depth/skin is an appearance candidate."})

def curved_artwork_plate(g,name,body,outline,surface,depth,color,rear=False,camber=.012):
    across=[-1,-.91,-.68,-.30,0,.30,.68,.91,1]
    vertices=[];steps=28
    lo=min(p[1] for p in outline)+.10;hi=max(p[1] for p in outline)-.10
    sign=-1 if rear else 1
    for py in np.linspace(lo,hi,steps):
        a,b=polygon_span(outline,float(py));cy=(CX-(a+b)/2)*SCALE;ry=max((b-a)*SCALE/2,.002)
        for t in across:
            y=sign*(cy+ry*t);z=(GROUND-py)*SCALE
            vertices.append([surface(y,z)+sign*camber*(1-t*t),y,z])
    n=len(across);count=len(vertices)
    vertices += [[x-sign*depth,y,z] for x,y,z in vertices]
    faces=[]
    for k in range(steps-1):
        for i in range(n-1):
            q=[k*n+i,k*n+i+1,(k+1)*n+i+1,(k+1)*n+i]
            faces.append(q);faces.append([v+count for v in reversed(q)])
        for i in (0,n-1):
            q=[k*n+i,(k+1)*n+i,(k+1)*n+i+count,k*n+i+count]
            faces.append(q if i==0 else list(reversed(q)))
    for k in (0,steps-1):
        for i in range(n-1):
            q=[k*n+i,k*n+i+count,k*n+i+1+count,k*n+i+1]
            faces.append(q if k==0 else list(reversed(q)))
    g.part(name,body,vertices,faces,color)
    g.parts[-1].update({"edge_bevel_m":0,"surface_shading":"curved_hard_surface","reference_outline_px":outline})

def continuous_crown(g):
    # Connect front shield and rear shell in actual 3D; no open black slot in TOP.
    sections=[(-.327,2.48,.385),(-.29,2.57,.380),(-.20,2.626,.35),(-.075,2.646,.315),
              (.045,2.597,.335),(.18,2.526,.325),(.30,2.457,.290),(.43,2.38,.250)]
    vertices=[]
    across=[-1,-.91,-.60,0,.60,.91,1]
    for x,z,width in sections:
        for t in across:vertices.append([x,t*width,z-.017*t*t])
    n=len(across);count=len(vertices)
    vertices += [[x,y,z-.025] for x,y,z in vertices]
    faces=[]
    for k in range(len(sections)-1):
        for i in range(n-1):
            q=[k*n+i,(k+1)*n+i,(k+1)*n+i+1,k*n+i+1]
            faces.append(q);faces.append([v+count for v in reversed(q)])
        for i in (0,n-1):
            q=[k*n+i,k*n+i+count,(k+1)*n+i+count,(k+1)*n+i]
            faces.append(q if i==0 else list(reversed(q)))
    for k in (0,len(sections)-1):
        for i in range(n-1):
            q=[k*n+i,k*n+i+1,k*n+i+1+count,k*n+i+count]
            faces.append(q if k==0 else list(reversed(q)))
    g.part("ivory_continuous_crown_bridge","torso",vertices,faces,IVORY)
    g.parts[-1].update({"edge_bevel_m":0,"surface_shading":"curved_hard_surface"})

def continuous_torso_shell(g,profiles):
    front=profiles["front"]["chest_ivory_outer"]
    back=[[x,y-612] for x,y in profiles["rear"]["rear_chest_ivory_outer"]]
    cheek=profiles["front"]["left_blue_chest_cheek_visible"]
    steps=48;vertices=[];faces=[];colors=[]
    for py in np.linspace(87.12,262.80,steps):
        a,b=polygon_span(front,float(py));yf=max((b-a)*SCALE/2,.003)
        back_py=min(max(py,min(p[1] for p in back)+.1),max(p[1] for p in back)-.1)
        ra,rb=polygon_span(back,float(back_py));yr=max((rb-ra)*SCALE/2,.003)
        if py>245:yr*=max(.35,1-(py-245)/25)
        ys=max(yf+.022,yr+.020)
        if min(p[1] for p in cheek)<py<max(p[1] for p in cheek):
            ca,cb=polygon_span(cheek,float(py));ys=max(ys,(CX-ca)*SCALE)
        z=(GROUND-py)*SCALE;xf=chest_front(0,z);xr=chest_back(0,z);xm=(xf-.10+xr+.047)/2
        recess=np.interp(z,[1.85,2.0,2.35,2.47],[0.,1.,1.,0.])
        xs=(xf-.10)*(1-recess)+min(xf-.10,.30)*recess
        ring=[(xf,yf*.80),(xf,-yf*.80),(xf-.012,-yf),(xs,-yf-.027),
              (xm,-ys),(xr+.047,-yr-.022),(xr,-yr*.92),(xr,yr*.92),
              (xr+.047,yr+.022),(xm,ys),(xs,yf+.027),(xf-.012,yf)]
        vertices.extend([[x,y,z] for x,y in ring])
    n=12;faces.append(list(reversed(range(n))));colors.append(IVORY)
    for k in range(steps-1):
        z=vertices[k*n][2]
        for i in range(n):
            faces.append([k*n+i,k*n+(i+1)%n,(k+1)*n+(i+1)%n,(k+1)*n+i])
            is_side=i in (3,4,8,9)
            # Blue cheeks are separate contour-constrained wraps below. A
            # blue-painted full torso side made their FRONT bottom a shelf
            # and hid the source's dark recessed mechanical layers.
            color=DARK if is_side and z<2.55 else IVORY
            if i in (4,8) and 1.89<z<2.55:color=BLUE
            if i in (5,6,7) and z<1.842:color=DARK
            colors.append(color)
    faces.append(list(range((steps-1)*n,steps*n)));colors.append(DARK)
    armor=[faces[0]]
    for k in range(steps-1):
        z=vertices[k*n][2]
        for i in (11,0,1,2,5,6,7):
            if i in (5,6,7) and z<1.846:continue
            armor.append([k*n+i,k*n+(i+1)%n,(k+1)*n+(i+1)%n,(k+1)*n+i])
    g.cover("continuous_ivory_torso_armor_cover","torso",vertices,armor,IVORY,.007,faces)
    g.parts[-1].update({"edge_bevel_m":0,"surface_shading":"curved_hard_surface",
        "reconstruction_note":"Continuous crown/front shield and shorter rear armor skins with open shoulder sides and visible thin returns. Assembly cavity is empty, not a colored torso solid.",
        "reference_front_outline_px":front,"reference_rear_outline_normalized_px":back})
    for side,sign in (("left",1),("right",-1)):
        frame=[];frame_faces=[]
        for py in np.linspace(108,242,28):
            z=(GROUND-py)*SCALE;ra,rb=polygon_span(back,float(py));yr=(rb-ra)*SCALE/2
            xr=chest_back(0,z)
            frame.extend([[xr+.032,sign*(yr+.021),z],[xr+.100,sign*(yr+.010),z]])
        for k in range(27):frame_faces.append([2*k,2*k+1,2*(k+1)+1,2*(k+1)])
        if sign<0:frame_faces=[list(reversed(f)) for f in frame_faces]
        g.cover(side+"_blue_rear_shoulder_edge_cover","torso",frame,frame_faces,BLUE,.006)
        g.parts[-1]["reconstruction_note"]="Narrow rear blue edge armor beside the shorter ivory back cover; shoulder cavity stays open instead of a blue or black side wall. Hidden support remains unknown."

def service_hatch(g,profiles):
    outline=[[x,y-612] for x,y in profiles["rear"]["rear_blue_service_hatch"]]
    center=np.mean(outline,axis=0)
    shadow=(center+1.035*(np.asarray(outline)-center)).tolist()
    g.panel("rear_service_door_shadow","torso",shadow,-.459,.010,DARK,.001,rear=True,camber=.001)
    g.panel("rear_blue_service_door","torso",outline,-.465,.010,BLUE,.002,rear=True,camber=.001)
    g.rounded_rect("rear_service_latch","torso",[-.469,0,2.320],.068,.026,.007,.007,DARK,True)
    g.rounded_rect("rear_door_upper_tab","torso",[chest_back(0,2.425)-.010,0,2.425],.048,.054,.015,.008,BLUE,True)
    for i,(px,py) in enumerate(((302,760),(347,760),(302,815),(347,815))):
        y,z=yz(px,py-612,True)
        g.bolt(f"rear_door_screw_{i}","torso",[-.470,y,z],axis=(-1,0,0),radius=.004)

def chest_cheek(g,side,sign,profiles):
    outline=profiles["front"]["left_blue_chest_cheek_visible"]
    if sign<0:outline=mirror_outline(outline)
    def forward(y,z):
        py=GROUND-z/SCALE
        ridge=(CX-edge_u_at_v([[273,196],[279,234]],py))*SCALE
        lateral=abs(y)
        # Two broad slanted bands rather than a continuous blue torso wall.
        bevel_drop=.040*max(0,(lateral-ridge)/.15)
        depth=float(np.interp(py,[162,184,212,223,237,250],[.22,.24,.28,.32,.28,.19]))
        # The cheek must sit behind the visible intake socket. The white
        # chest's much more forward arc is not the blue cheek's depth.
        return depth-min(.06,bevel_drop)
    fitted_guard(g,side+"_blue_chest_cheek_wrap","torso",outline,forward,
        lambda y,z:-.190+.028*(z-2.1),BLUE,
        outer_bevel=.003,inset_height=.002,inset_ratio=.97,open_cover=True)
    g.parts[-1].update({"auto_smooth_angle_deg":30,
        "reference_front_feature_edges_px":[[[273,196],[279,234]],[[251,216],[270,219]]],
        "reconstruction_note":"Visible FRONT blue cheek color region and diagonal taper restored; side/rear depth is an uncalibrated wrap candidate. The dark torso carrier is distinct."})

def rear_leg_cover(g,side,sign,profiles):
    outline=profiles["left"]["middle_leg_blue_rear_cap_visible"]
    vertices=[[(971-u)*SCALE,sign*.607,(GROUND-v)*SCALE] for u,v in outline]
    face=list(range(len(vertices)))
    normal=sum((np.cross(np.asarray(vertices[face[i]])-vertices[0],
        np.asarray(vertices[face[i+1]])-vertices[0]) for i in range(1,len(face)-1)),start=np.zeros(3))
    if normal[1]*sign<0:face.reverse()
    g.cover(side+"_blue_middle_shank_rear_cover",side+"_middle_shank",vertices,[face],BLUE,.006)
    g.parts[-1].update({"reference_left_outline_px":outline,
        "reconstruction_note":"Observed small rear blue knee-to-fold armor cover, with thin skin/open mounting back. Y attachment position and hidden support are candidates; it does not replace the dark carrying bridge."})

def refine_volumes(g,spec):
    landmarks=json.loads((ROBOT/"source/appearance_c_reference_landmarks.json").read_text())
    profiles={v:{p["id"]:p["global_uv_px"] for p in info["profiles"]} for v,info in landmarks["views"].items()}
    front_edges={p["id"]:p.get("feature_edges_global_uv_px",[]) for p in landmarks["views"]["front"]["profiles"]}
    shape_path=ROBOT/"source/appearance_c_front_shape_constraints.json"
    shoulder_shape=json.loads(shape_path.read_text())
    if shoulder_shape["source_sha256"]!=spec["appearance_authority"]["sha256"]:
        raise ValueError("FRONT shape constraints belong to a different artwork")
    shoulder_visible_outline=(shoulder_shape["observed_background_or_dark_mechanism_outer_arc"]["points_uv"]+
        list(reversed(shoulder_shape["observed_outer_blue_occlusion_edge"]["points_uv"]))[1:-1])
    remove=["ivory_continuous_front_carapace","ivory_long_shield_face","ivory_crown_top_lip","ivory_back_carapace","dark_torso_inner_layer",
            "saffron_front_pelvis","saffron_pelvis_front_inset","ivory_rear_sacral_cover","rear_saffron_crossbar"]
    for side in ("left","right"):
        remove += [side+suffix for suffix in ("_blue_shoulder_swept_top","_blue_shoulder_front_fold","_blue_rear_shoulder",
            "_blue_forearm_outer","_blue_forearm_long_plane","_blue_deltoid_outer","_blue_deltoid_front_plane",
            "_ivory_shoulder_cap","_ivory_upper_arm_link_cover","_ivory_upper_arm_inner_fold",
            "_blue_thigh_armor","_blue_thigh_front_facet","_blue_middle_shank","_blue_shank_front_plane",
            "_blue_chest_flank","_blue_lower_chest_flange","_gold_knee_guard","_gold_knee_center_face","_ivory_hip_cuff")]
    remove += ["rear_service_door_shadow","rear_blue_service_door","rear_service_latch","rear_door_upper_tab"]
    g.parts=[p for p in g.parts if p["name"] not in remove and "radiator_" not in p["name"] and "vent_fastener" not in p["name"] and not p["name"].startswith("rear_door_screw_")]
    continuous_torso_shell(g,profiles)
    service_hatch(g,profiles)
    curved_artwork_plate(g,"ivory_crown_inset","torso",profiles["front"]["crown_ivory_inset"],lambda y,z:chest_front(y,z)+.014,.009,[.95,.93,.87,1],camber=.013)
    curved_artwork_plate(g,"saffron_front_pelvis_cartridge","pelvis",profiles["front"]["pelvis_front_yellow_cartridge"],
        lambda y,z:.305+.014*(z-1.40),.075,GOLD,camber=.010)
    curved_artwork_plate(g,"ivory_rear_pelvis_cartridge","pelvis",[[x,y-612] for x,y in profiles["rear"]["rear_long_ivory_pelvis_cartridge"]],
        lambda y,z:-.217,.043,IVORY,rear=True,camber=.008)
    for side in ("left","right"):
        curved_artwork_plate(g,side+"_rear_yellow_pelvis_band","pelvis",[[x,y-612] for x,y in profiles["rear"]["rear_"+side+"_yellow_pelvis_band_visible"]],
            lambda y,z:-.195,.037,GOLD,rear=True,camber=.008)
    for part in g.parts:
        if part["name"]=="dark_torso_inner_layer":
            # Keep the visible carrier inside the blue/ivory envelope so it
            # cannot incorrectly occlude the art's blue inner cheek.
            for v in part["vertices_world_m"]:v[0]=.60*v[0]-.035;v[1]*=.90
    for side,s in (("left",1),("right",-1)):
        shoulder_sweep(g,side,s,profiles)
        chest_cheek(g,side,s,profiles)
        fitted_radiator(g,side,s,profiles)
        hip_outline=profiles["front"]["left_hip_ivory_connector"]
        g.panel(side+"_ivory_hip_cuff",side+"_thigh",hip_outline if s==1 else mirror_outline(hip_outline),
            lambda y,z:.285+.020*(z-1.74),.068,IVORY,.003,camber=.004)
        g.parts[-1]["reconstruction_note"]="Observed FRONT slanted ivory hip connector moved to its actual visible region; depth/hidden attachment is an appearance candidate."
        dual_view_shell(g,side+"_blue_forearm_wrap",side+"_forearm",profiles["front"]["left_forearm_blue_outer"],profiles["left"]["forearm_blue_outer"],BLUE,s,18,
            front_edges["left_forearm_blue_outer"][1:3],"forearm")
        dual_view_shell(g,side+"_blue_deltoid_wrap",side+"_upper_arm",profiles["front"]["left_upper_arm_blue_outer_guard"],profiles["left"]["upper_arm_blue_outer_guard"],BLUE,s,12,
            front_edges["left_upper_arm_blue_outer_guard"],"deltoid")
        dual_view_shell(g,side+"_ivory_shoulder_cap",side+"_upper_arm",
            shoulder_visible_outline,
            [[990,132],[1008,137],[1020,151],[1024,167],[1019,182],[1004,191],[982,195],[961,184],[949,172],[951,155],[962,141],[978,134]],IVORY,s,12)
        g.parts[-1].update({"visible_region_source":str(shape_path.relative_to(ROOT)),
            "visible_region_uncertainty_px":3,
            "reconstruction_note":"Only the observed exposed FRONT white shoulder region is constrained; blue occlusion edge does not specify the hidden white shell. LEFT and hidden closure remain uncalibrated candidates."})
        dual_view_shell(g,side+"_ivory_lower_upper_arm",side+"_upper_arm",profiles["front"]["left_upper_arm_lower_ivory_guard"],
            [[967,197],[979,202],[1000,216],[1004,236],[995,254],[984,260],[970,237],[955,212]],IVORY,s,12)
        dual_view_shell(g,side+"_blue_thigh_wrap",side+"_thigh",profiles["front"]["left_thigh_blue_outer"],
            [[970,269],[949,283],[927,301],[916,318],[902,336],[897,350],[909,368],[929,382],[943,376],[965,351],[984,321],[987,299],[980,279]],BLUE,s,18,
            front_edges["left_thigh_blue_outer"],"thigh")
        dual_view_shell(g,side+"_blue_middle_shank_wrap",side+"_middle_shank",profiles["front"]["left_middle_leg_blue_outer"],profiles["left"]["middle_leg_blue_outer"],BLUE,s,15,
            front_edges["left_middle_leg_blue_outer"][1:2],"middle_shank")
        rear_leg_cover(g,side,s,profiles)
        knee_outline=profiles["front"]["left_knee_yellow_insert"]
        if s<0:knee_outline=mirror_outline(knee_outline)
        side_guard=profiles["left"]["knee_yellow_insert"]
        def guard_depth(y,z,front=True):
            py=np.clip(GROUND-z/SCALE,349.15,408.85)
            a,b=polygon_span(side_guard,float(py))
            return (971-(a if front else b))*SCALE
        def guard_front(y,z):
            py=GROUND-z/SCALE
            ridge=(CX-edge_u_at_v(front_edges["left_knee_yellow_insert"][0],py))*SCALE
            d=abs(y)-ridge
            drop=min(.045,.034*max(0,d/.10)+.008*max(0,-d/.12))
            return max(guard_depth(y,z)-drop,guard_depth(y,z,False)+.013)
        fitted_guard(g,side+"_yellow_front_knee_insert",side+"_thigh",knee_outline,
            guard_front,lambda y,z:guard_depth(y,z,False),GOLD,
            outer_bevel=.003,inset_height=.002,inset_ratio=.95,open_cover=True)
        g.parts[-1].update({"reference_front_feature_edges_px":front_edges["left_knee_yellow_insert"],
            "reconstruction_note":"FRONT yellow knee color boundary and broad vertical fold restored; visible LEFT depth trend retained, side caps and hidden closure are uncalibrated."})
        knee_rear=[[x,y-612] for x,y in profiles["rear"]["rear_left_knee_yellow_insert"]]
        if s>0:knee_rear=mirror_outline(knee_rear)
        fitted_guard(g,side+"_yellow_rear_knee_insert",side+"_thigh",knee_rear,
            lambda y,z:-.10+.030*(z-1.10),lambda y,z:-.065+.030*(z-1.10),GOLD,rear=True,open_cover=True)
        # Preserve original gold markers on the actual new front surfaces.
        for part in g.parts:
            if not part["name"].startswith(side+"_"):continue
            if "forearm_gold_marker" in part["name"]:
                for v in part["vertices_world_m"]:v[0]-=.207
            if "deltoid_gold_marker" in part["name"]:
                for v in part["vertices_world_m"]:v[0]-=.185
            if "upper_arm_gold_marker" in part["name"]:
                for v in part["vertices_world_m"]:v[0]-=.170
            if "gold_knee" in part["name"]:
                for v in part["vertices_world_m"]:
                    v[0] += float(np.interp(v[2],[1.025,1.11,1.25,1.34],[.055,.105,.165,.125]))
            if "thigh_small_marker" in part["name"]:
                for v in part["vertices_world_m"]:v[0]-=.195
        # Blue U-yokes frame the small elbow barrel rather than leave a bare rod.
        outline=profiles["front"]["left_elbow_blue_yoke_visible"]
        g.panel(side+"_blue_elbow_yoke",side+"_upper_arm",outline if s==1 else mirror_outline(outline),
                -.100,.036,BLUE,.004,camber=.005)

def project_surface_details(g):
    """Attach reference seams/markers to the actual curved armor, along +X."""
    parts={p["name"]:p for p in g.parts}
    bindings={"forearm_gold_marker":"blue_forearm_wrap","forearm_upper_edge":"blue_forearm_wrap",
        "deltoid_gold_marker":"blue_deltoid_wrap","upper_arm_gold_marker":"ivory_lower_upper_arm",
        "thigh_small_marker":"blue_thigh_wrap","knee_small_marker":"yellow_front_knee_insert",
        "shank_small_marker":"blue_middle_shank_wrap"}
    rebuilt_edges=[]
    for part in list(g.parts):
        side=next((s for s in ("left","right") if part["name"].startswith(s+"_")),None)
        if not side:continue
        target=next((suffix for token,suffix in bindings.items() if token in part["name"]),None)
        if not target:continue
        surface=parts[side+"_"+target]
        v=np.asarray(surface["vertices_world_m"])
        triangles=np.asarray([[v[f[0]],v[f[i]],v[f[i+1]]] for f in surface["faces"] for i in range(1,len(f)-1)])
        if "forearm_upper_edge" in part["name"]:
            # The original edge lies on the silhouette. Moving individual tube
            # vertices to that silhouette collapses the tube's cross section.
            # Rebuild short closed segments around the projected centreline.
            original=np.asarray(part["vertices_world_m"])
            a,b=original[:8].mean(0),original[8:].mean(0)
            line=[];max_shift=0.
            for t in np.linspace(0,1,max(3,int(np.linalg.norm(b-a)/.012)+1)):
                p=(1-t)*a+t*b;hits=[];nearest=None
                for tri in triangles:
                    yz_point=p[1:];aa,bb,cc=tri[:,1:]
                    mat=np.column_stack((bb-aa,cc-aa))
                    if abs(np.linalg.det(mat))>1e-12:
                        uv=np.linalg.solve(mat,yz_point-aa)
                        w=np.array([1-uv.sum(),uv[0],uv[1]])
                        if w.min()>=-1e-7:hits.append(float(w@tri[:,0]))
                    for i,j in ((0,1),(1,2),(2,0)):
                        d=tri[j,1:]-tri[i,1:]
                        u=np.clip(np.dot(yz_point-tri[i,1:],d)/max(np.dot(d,d),1e-20),0,1)
                        q=(1-u)*tri[i]+u*tri[j];distance=np.linalg.norm(q[1:]-yz_point)
                        if nearest is None or distance<nearest[0]-1e-8 or (abs(distance-nearest[0])<=1e-8 and q[0]>nearest[1][0]):nearest=(distance,q)
                if hits:p[0]=max(hits)+.001
                else:
                    max_shift=max(max_shift,nearest[0]);p=nearest[1].copy();p[0]+=.001
                line.append(p)
            g.parts.remove(part)
            first=len(g.parts)
            g.tube(part["name"],part["body"],line,.0012,DARK,8)
            for edge in g.parts[first:]:
                edge.update({"attached_surface_part":surface["name"],
                    "surface_projection_unresolved_vertices":0,
                    "centreline_max_yz_attachment_shift_m":max_shift,
                    "reconstruction_note":"Thin opening seam rebuilt around the actual forearm surface; native closed cross section retained."})
                rebuilt_edges.append(edge)
            continue
        center_x=np.mean([p[0] for p in part["vertices_world_m"]])
        misses=0
        for p in part["vertices_world_m"]:
            yz_point=np.array(p[1:]);hits=[];nearest=None
            for tri in triangles:
                a,b,c=tri[:,1:]
                mat=np.column_stack((b-a,c-a));det=np.linalg.det(mat)
                if abs(det)>1e-12:
                    uv=np.linalg.solve(mat,yz_point-a)
                    weights=np.array([1-uv.sum(),uv[0],uv[1]])
                    if weights.min()>=-1e-7:hits.append(float(weights@tri[:,0]))
                for i,j in ((0,1),(1,2),(2,0)):
                    delta=tri[j,1:]-tri[i,1:]
                    t=np.clip(np.dot(yz_point-tri[i,1:],delta)/max(np.dot(delta,delta),1e-20),0,1)
                    q=(1-t)*tri[i]+t*tri[j];distance=np.linalg.norm(q[1:]-yz_point)
                    if nearest is None or distance<nearest[0]-1e-8 or (abs(distance-nearest[0])<=1e-8 and q[0]>nearest[1][0]):nearest=(distance,q)
            old_relative=p[0]-center_x
            if hits:p[0]=max(hits)+.002+old_relative
            elif nearest is not None and nearest[0]<.011:
                p[0]=float(nearest[1][0])+.002+old_relative
                p[1:]=nearest[1][1:].tolist()
            else:misses+=1
        part["attached_surface_part"]=surface["name"]
        part["edge_bevel_m"]=0
        part["surface_projection_unresolved_vertices"]=misses
        part["reconstruction_note"]="Original small marker/edge projected onto the actual armor surface; no floating decorative rods."

def build(spec):
    g=Geometry(spec)
    # The narrow-tip main shield and thin crown are separate original features.
    g.panel("ivory_continuous_front_carapace","torso",
        [[254,101],[272,90],[302,86],[348,86],[380,91],[398,103],
         [387,138],[367,185],[340,258],[330,263],[315,262],[289,198],[272,153],[261,121]],
        chest_front,.039,IVORY,.007,camber=.012)
    g.panel("ivory_crown_top_lip","torso",
        [[257,101],[274,91],[303,87],[349,87],[378,92],[394,101],
         [378,111],[356,114],[296,114],[279,112]],
        lambda y,z:chest_front(y,z)+.014,.018,[.95,.93,.87,1],.004,camber=.008)
    g.panel("ivory_long_shield_face","torso",
        [[279,124],[294,118],[357,118],[373,125],[365,164],[353,199],
         [335,252],[326,259],[316,255],[299,206],[288,171]],
        lambda y,z:chest_front(y,z)+.020,.012,IVORY,.005,camber=.008)
    # Inset panel line around the crown, as shown on FRONT and TOP.
    g.seam("crown_top_panel_line","torso",[[274,99],[288,109],[361,109],[376,99]],
           lambda y,z:chest_front(y,z)+.034,.0012,color=[.46,.45,.41,1])
    for i,(px,py) in enumerate(((278,102),(296,111),(356,111),(375,102))):
        y,z=yz(px,py);g.bolt(f"crown_fastener_{i}","torso",[chest_front(y,z)+.037,y,z],radius=.004)
    # Back has a broad trapezoidal shell; rear pixel coordinates are normalized
    # to FRONT origin (the original REAR panel ground is 1215 rather than 603).
    rear_outline=[[244,109],[262,98],[298,92],[349,91],[381,100],[400,110],
                  [391,142],[383,194],[381,226],[369,253],[342,260],[294,260],
                  [273,251],[262,224],[257,194],[251,146]]
    g.panel("ivory_back_carapace","torso",rear_outline,chest_back,.039,IVORY,.007,rear=True,camber=.009)
    # Open dark carrier: hidden in front by the original ivory/blue armor.
    g.loft("dark_torso_inner_layer","torso",[
        ([.00,0,1.75],.13,.22),([.05,0,1.94],.23,.29),
        ([.03,0,2.15],.27,.37),([-.045,0,2.38],.25,.40),([-.10,0,2.54],.16,.35)],DARK,True,square=True)
    for side,s in (("left",1),("right",-1)):
        def out(p): return p if s==1 else mirror_outline(p)
        # Chest sides retain the staggered shoulders, vents and lower blue flanges.
        g.panel(side+"_blue_chest_flank","torso",out([
            [252,147],[275,145],[291,192],[307,250],[289,252],[273,244],
            [250,238],[244,221],[245,190]]),
            lambda y,z:.30+(.15 if z>2.08 else .02),.25,BLUE,.010,camber=.025)
        g.panel(side+"_blue_lower_chest_flange","torso",out([
            [253,212],[272,208],[290,243],[302,256],[277,251],[260,243],[252,228]]),
            lambda y,z:.35,.08,BLUE,.006,camber=.012)
        # Swept compact shoulders, in contrast to the rejected inflated blobs.
        g.panel(side+"_blue_shoulder_swept_top","torso",out([
            [212,113],[220,107],[251,101],[259,108],[269,127],[277,150],
            [259,154],[239,147],[225,132],[216,124]]),
            lambda y,z:.075+.10*(2.60-z),.38,BLUE,.012,camber=.017)
        g.panel(side+"_blue_shoulder_front_fold","torso",out([
            [218,121],[240,124],[266,146],[277,151],[261,157],[238,150],[225,137]]),
            .15,.046,[.012,.49,.79,1],.006,camber=.010)
        # Rear visible shoulder is slightly behind the crown.
        g.panel(side+"_blue_rear_shoulder","torso",out([
            [210,120],[218,113],[248,107],[266,129],[274,145],[252,150],[223,142]]),
            -.25,.055,BLUE,.009,rear=True,camber=.012)
        # Radiators have rounded inset frames, black wells and narrow louvers.
        y=s*(CX-260)*SCALE;z=(GROUND-185)*SCALE
        g.rounded_rect(side+"_radiator_ivory_socket","torso",[.477,y,z],.174,.333,.025,.034,IVORY)
        g.rounded_rect(side+"_radiator_gold_trim","torso",[.489,y,z],.137,.287,.012,.023,GOLD)
        g.rounded_rect(side+"_radiator_black_well","torso",[.493,y,z],.112,.266,.018,.016,BLACK)
        for i in range(13):
            zz=z-.120+i*.020
            g.box(side+f"_radiator_louver_{i:02}","torso",[.498,y,zz],[.007,.093,.0055],[.29,.29,.25,1],True)
            g.parts[-1]["edge_bevel_m"] = .001
        for zz in (z-.13,z+.13):
            for dy in (-.060,.060):
                g.bolt(side+f"_vent_fastener_{zz:.3f}_{dy:.3f}".replace("-","n").replace(".","p"),"torso",[.502,y+dy,zz],radius=.0038)
    # Slim vertical central indicator, flush with the long shield.
    zz=(GROUND-200)*SCALE;xx=chest_front(0,zz)+.042
    g.rounded_rect("central_indicator_recess","torso",[xx,0,zz],.069,.248,.010,.010,DARK)
    g.rounded_rect("central_indicator_gold_frame","torso",[xx+.002,0,zz],.054,.220,.006,.007,GOLD)
    g.rounded_rect("central_indicator_lit_strip","torso",[xx+.007,0,zz],.025,.185,.004,.004,[1,.83,.32,1])
    # Back service door follows REAR: rounded corners, inset dark seam, four screws.
    g.rounded_rect("rear_service_door_shadow","torso",[-.354,0,2.180],.310,.400,.010,.037,DARK,True)
    g.rounded_rect("rear_blue_service_door","torso",[-.359,0,2.180],.290,.380,.012,.027,BLUE,True)
    g.rounded_rect("rear_service_latch","torso",[-.374,0,2.320],.068,.026,.009,.007,DARK,True)
    g.rounded_rect("rear_door_upper_tab","torso",[-.336,0,2.425],.048,.054,.015,.008,BLUE,True)
    for i,(y,z) in enumerate(((-.113,2.027),(.113,2.027),(-.113,2.33),(.113,2.33))):
        g.bolt(f"rear_door_screw_{i}","torso",[-.377,y,z],axis=(-1,0,0),radius=.005)
    g.seam("rear_crown_panel_seam","torso",[[280,107],[296,131],[352,131],[370,107]],
           lambda y,z:chest_back(y,z)-.016,.0013,rear=True,color=[.46,.45,.41,1])
    # Short ivory coupler under the shield, then a compact saffron pelvis.
    g.panel("ivory_central_waist_coupler","pelvis",[[308,263],[342,263],[338,275],[314,275]],.23,.10,IVORY,.007,camber=.004)
    g.loft("dark_pelvis_inner_layer","pelvis",[([0,0,1.43],.105,.16),([0,0,1.62],.14,.18),([0,0,1.75],.12,.15)],DARK,True,square=True)
    g.panel("saffron_front_pelvis","pelvis",[[300,278],[308,275],[338,275],[348,282],
        [342,322],[336,344],[314,344],[305,322]],.302,.103,GOLD,.009,camber=.009)
    g.panel("saffron_pelvis_front_inset","pelvis",[[308,284],[335,284],[340,291],[333,333],[318,333]],.323,.007,[1,.69,.20,1],.004,camber=.003)
    g.rounded_rect("pelvis_front_black_latch","pelvis",[.339,0,1.410],.044,.061,.008,.008,DARK)
    g.panel("ivory_rear_sacral_cover","pelvis",[[307,294],[337,294],[335,340],[329,353],[316,353],[310,340]],-.217,.043,IVORY,.008,rear=True,camber=.01)
    g.panel("rear_saffron_crossbar","pelvis",[[274,278],[285,270],[312,276],[336,276],[360,270],[372,278],[369,286],[283,286]],-.195,.065,GOLD,.007,rear=True,camber=.008)
    for side,s in (("left",1),("right",-1)):
        def out(p):return p if s==1 else mirror_outline(p)
        sh=spec["points_world_m"][side+"_shoulder"]
        el=spec["points_world_m"][side+"_elbow"]
        # Upper shoulder porcelain cap and compact outer swept deltoid.
        g.panel(side+"_ivory_shoulder_cap",side+"_upper_arm",out([
            [202,130],[213,126],[221,136],[226,153],[225,170],[211,188],
            [198,178],[188,161],[190,145]]),.12,.22,IVORY,.009,camber=.022)
        g.panel(side+"_blue_deltoid_outer",side+"_upper_arm",out([
            [184,151],[195,153],[200,169],[197,194],[194,214],[172,217],
            [153,206],[160,183],[172,161]]),.15,.25,BLUE,.009,camber=.025)
        g.panel(side+"_blue_deltoid_front_plane",side+"_upper_arm",out([
            [185,155],[193,161],[195,184],[185,204],[167,208],[162,202],[170,183]]),
            .175,.021,[.013,.61,.92,1],.004,camber=.008)
        g.panel(side+"_ivory_upper_arm_link_cover",side+"_upper_arm",out([
            [204,184],[220,192],[229,210],[218,233],[204,250],[185,243],
            [182,230],[190,207]]),.165,.16,IVORY,.009,camber=.019)
        g.panel(side+"_ivory_upper_arm_inner_fold",side+"_upper_arm",out([
            [208,199],[219,211],[210,236],[203,244],[193,238],[197,218]]),
            .19,.015,[.96,.94,.87,1],.004,camber=.005)
        # Thick outward-biased blue forearm with slanted upper and lower openings.
        g.panel(side+"_blue_forearm_outer",side+"_forearm",out([
            [156,260],[181,269],[203,282],[208,307],[201,340],[190,359],
            [167,362],[146,370],[141,350],[138,309],[141,278]]),
            lambda y,z:.20+.022*math.sin((z-1.22)/.56*math.pi),.26,BLUE,.012,camber=.034)
        g.panel(side+"_blue_forearm_long_plane",side+"_forearm",out([
            [159,272],[176,276],[193,286],[196,307],[187,342],[177,355],[150,364],[147,343],[147,305]]),
            lambda y,z:.241+.012*math.sin((z-1.22)/.56*math.pi),.018,[.015,.61,.93,1],.006,camber=.008)
        # Upper lip is a separate bent edge, with an actual dark gap around the joint.
        g.seam(side+"_forearm_upper_edge",""+side+"_forearm",out([[151,263],[170,269],[188,278],[203,287]]),.211,.0022,color=DARK)
        for tag,pixels,xpos in (("deltoid",[[185,181],[190,177],[193,199],[189,202]],.190),
                               ("upper_arm",[[196,228],[200,228],[196,241],[192,240]],.216),
                               ("forearm",[[170,338],[175,337],[173,351],[169,352]],.267)):
            body=side+("_upper_arm" if tag!="forearm" else "_forearm")
            g.panel(side+"_"+tag+"_gold_marker",body,out(pixels),xpos,.008,GOLD,.002,camber=.002)
        # Ivory hip transition, blue thigh and the separate faceted yellow guard.
        g.panel(side+"_ivory_hip_cuff",side+"_thigh",out([
            [271,250],[287,249],[300,260],[296,269],[287,278],[272,271],[265,260]]),.090,.15,IVORY,.007,camber=.006)
        g.panel(side+"_blue_thigh_armor",side+"_thigh",out([
            [246,269],[268,270],[279,283],[290,309],[298,341],[297,364],
            [286,382],[272,393],[235,390],[221,377],[216,349],[220,315],[230,286]]),
            lambda y,z:.13+.070*math.sin((z-1.1)/.55*math.pi),.28,BLUE,.011,camber=.026)
        g.panel(side+"_blue_thigh_front_facet",side+"_thigh",out([
            [248,275],[264,277],[275,300],[282,332],[279,350],[250,348],[234,358],
            [228,340],[233,304]]),.222,.018,[.014,.61,.92,1],.007,camber=.005)
        g.panel(side+"_gold_knee_guard",side+"_thigh",out([
            [243,342],[273,348],[285,375],[280,392],[268,402],[243,399],[231,387],[231,368]]),
            .274,.082,GOLD,.008,camber=.012)
        g.panel(side+"_gold_knee_center_face",side+"_thigh",out([
            [247,349],[267,351],[278,376],[270,393],[250,390],[240,377]]),
            .293,.008,[1,.69,.20,1],.004,camber=.006)
        # Middle leg sweeps rearward in depth; deliberately asymmetrical armor.
        g.panel(side+"_blue_middle_shank",side+"_middle_shank",out([
            [218,429],[241,427],[266,431],[277,442],[275,464],[265,491],
            [244,504],[218,499],[207,484],[202,457],[205,441]]),
            lambda y,z:float(np.interp(z,[.52,.70,.88],[.065,.19,.275])),.19,BLUE,.010,camber=.020)
        g.panel(side+"_blue_shank_front_plane",side+"_middle_shank",out([
            [222,434],[243,435],[263,439],[259,466],[243,496],[222,493],[211,477],[211,454]]),
            lambda y,z:float(np.interp(z,[.52,.70,.88],[.093,.215,.305])),.015,[.02,.61,.92,1],.006,camber=.008)
        g.panel(side+"_blue_distal_front_guard",side+"_distal_shank",out([
            [213,513],[239,514],[246,531],[239,543],[207,541],[208,528]]),
            .055,.055,BLUE,.006,camber=.009)
        g.panel(side+"_ivory_distal_side_tab",side+"_distal_shank",out([
            [245,524],[252,528],[250,543],[240,548],[238,542]]),-.035,.022,IVORY,.004,camber=.004)
        for tag,pixels,xpos in (("thigh",[[261,281],[265,281],[263,291],[260,291]],.224),
                               ("knee",[[234,366],[239,363],[237,378],[233,379]],.290),
                               ("shank",[[208,447],[211,446],[210,458],[207,458]],.231)):
            body=side+("_thigh" if tag!="shank" else "_middle_shank")
            g.panel(side+"_"+tag+"_small_marker",body,out(pixels),xpos,.004,GOLD if tag!="knee" else METAL,.001,camber=.001)
    refine_volumes(g,spec)
    from gorilla_appearance_mechanics import add_mechanics
    first_mechanics=len(g.parts)
    add_mechanics(g,spec["points_world_m"],PALETTE)
    # These parts already have native bevel/lathe profiles. Additional blanket
    # bevels collapsed tiny ring/knuckle edges in round-three GLB topology.
    for part in g.parts[first_mechanics:]:part["edge_bevel_m"]=0
    for part in g.parts:
        if any(token in part["name"] for token in ("small_marker","ivory_central_waist_coupler","ivory_distal_side_tab")):
            part["edge_bevel_m"]=0
    project_surface_details(g)
    return g

def main():
    p=argparse.ArgumentParser(description=__doc__)
    p.add_argument("--spec",type=Path,default=ROBOT/"configs/appearance_c_spec.json")
    p.add_argument("--output",type=Path,default=ROBOT/"cad/source/appearance_c_scene.json")
    args=p.parse_args()
    spec=json.loads(args.spec.read_text())
    image=ROBOT/spec["appearance_authority"]["path"]
    if sha(image)!=spec["appearance_authority"]["sha256"]:raise ValueError("Sole artwork identity changed")
    g=build(spec)
    v=np.concatenate([np.array(p["vertices_world_m"]) for p in g.parts])
    scripts=[Path(__file__),Path(__file__).with_name("gorilla_appearance_mechanics.py"),Path(__file__).with_name("build_gorilla_proportion_layout.py"),ROBOT/"source/appearance_c_reference_landmarks.json",ROBOT/"source/appearance_c_front_shape_constraints.json"]
    scene={
        "schema":"gorilla_appearance_scene_v2","robot_id":"gorilla_v0_1","checkpoint_id":"gorilla_appearance_c",
        "spec_path":str(args.spec.relative_to(ROOT)),"spec_sha256":sha(args.spec),
        "appearance_authority_path":str(image.relative_to(ROOT)),"image_sha256":sha(image),
        "units":"m","coordinate_frame":spec["coordinate_frame"],"rgba_encoding":"sRGB converted to linear by renderer",
        "parts":g.parts,"bounds_world_m":[v.min(axis=0).tolist(),v.max(axis=0).tolist()],"dimensions_xyz_m":np.ptp(v,axis=0).tolist(),
        "build_inputs":[{"path":str(x.relative_to(ROOT)),"sha256":sha(x)} for x in scripts],
        "physical_parameters_status":"not_assigned_appearance_reconstruction_only",
        "appearance_accepted":False,"physics_accepted":False,
        "uncertainties":["Artwork cameras, illumination and four-view poses are not calibrated.","Hidden depths and unseen mechanism surfaces are reconstructed candidates.","Display grouping uses historical body names; it is not a new physical joint contract.","Explicit bevel modifiers are applied identically before all rendering and export."],
    }
    args.output.parent.mkdir(parents=True,exist_ok=True)
    args.output.write_text(json.dumps(scene,indent=2)+"\n")
    print(json.dumps({"scene":str(args.output),"parts":len(g.parts),"dimensions_xyz_m":scene["dimensions_xyz_m"]}))

if __name__=="__main__":main()

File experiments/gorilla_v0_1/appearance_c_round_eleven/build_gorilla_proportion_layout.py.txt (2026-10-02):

#!/usr/bin/env python3
"""Build editable appearance geometry from the sole AA3 authority and layout B.

This is a reconstruction candidate, not manufacturing CAD or an appearance pass.
The closed panel meshes support conservative surface-area shell accounting.
Hardware visualization has zero shell thickness to avoid double-counting hardware.
"""
from __future__ import annotations

import argparse
import hashlib
import json
import math
from pathlib import Path

import numpy as np

ROOT = Path(__file__).resolve().parents[2]
ROBOT = ROOT / "robots/gorilla_v0_1"
IVORY = [0.88, 0.845, 0.735, 1]
BLUE = [0.008, 0.40, 0.76, 1]
GOLD = [1.0, 0.51, 0.025, 1]
DARK = [0.045, 0.052, 0.057, 1]
METAL = [0.17, 0.18, 0.18, 1]
BLACK = [0.009, 0.012, 0.015, 1]

def sha(path: Path) -> str:
    return hashlib.sha256(path.read_bytes()).hexdigest()

class Geometry:
    def __init__(self, spec: dict):
        self.spec = spec
        self.parts: list[dict] = []
        self.bodies = {spec["root_body"], *(j["child"] for j in spec["joints"])}

    def part(self, name, body, vertices, faces, color, hardware=False, note=""):
        assert body in self.bodies, body
        vertices=np.asarray(vertices,float)
        assert np.isfinite(vertices).all(), name
        volume=sum(np.dot(vertices[f[0]],np.cross(vertices[f[i]],vertices[f[i+1]]))/6
                   for f in faces for i in range(1,len(f)-1))
        if volume < 0: faces=[list(reversed(f)) for f in faces]
        self.parts.append({
            "name": name, "body": body,
            "role": "decoration" if hardware else "armor",
            "vertices_world_m": np.round(vertices, 8).tolist(),
            "faces": [list(map(int, f)) for f in faces], "rgba": color,
            "shell_density_kg_m3": 2700, "shell_thickness_m": 0 if hardware else .003,
            "mass_basis_note": note or ("Visual representation of independently counted hardware/frame; no additional shell mass." if hardware else "Closed appearance panel; surface-area thin-shell estimate, not a solid billet."),
        })

    def loft(self, name, body, rings, color, hardware=False, n=16, square=False):
        """Rings are (world center, depth/2, width/2), stacked in local Z."""
        verts = []
        if square:
            # Chamfered rectangle, preserving an editable mostly-quad control cage.
            profile = [(1,.66),(.66,1),(-.66,1),(-1,.66),(-1,-.66),(-.66,-1),(.66,-1),(1,-.66)]
            n = len(profile)
        else:
            profile = [(math.cos(2*math.pi*i/n), math.sin(2*math.pi*i/n)) for i in range(n)]
        for center, rx, ry in rings:
            c = np.asarray(center)
            verts.extend([c + [rx*x, ry*y, 0] for x,y in profile])
        faces = [list(reversed(range(n)))]
        for k in range(len(rings)-1):
            for i in range(n):
                j = (i+1)%n
                faces.append([k*n+i, k*n+j, (k+1)*n+j, (k+1)*n+i])
        faces.append(list(range((len(rings)-1)*n, len(rings)*n)))
        self.part(name, body, np.asarray(verts), faces, color, hardware)

    def link(self, name, body, a, b, profiles, color, hardware=False, n=16):
        a,b = np.asarray(a,float), np.asarray(b,float)
        axis = (b-a)/np.linalg.norm(b-a)
        width = np.array([0.,1.,0.]) if abs(axis[1]) < .95 else np.array([0.,0.,1.])
        width -= axis*np.dot(axis,width)
        width /= np.linalg.norm(width)
        depth = np.cross(width,axis)
        # Positive depth aims forward wherever the limb is roughly vertical.
        if depth[0] < 0: depth *= -1
        verts = []
        for t, rx, ry in profiles:
            c = a+t*(b-a)
            for i in range(n):
                angle = 2*math.pi*i/n
                verts.append(c+rx*math.cos(angle)*depth+ry*math.sin(angle)*width)
        faces=[list(reversed(range(n)))]
        for k in range(len(profiles)-1):
            for i in range(n):
                j=(i+1)%n
                faces.append([k*n+i,k*n+j,(k+1)*n+j,(k+1)*n+i])
        faces.append(list(range((len(profiles)-1)*n,len(profiles)*n)))
        # The frame can have opposite orientation depending on link direction.
        va=np.asarray(verts)
        volume=sum(np.dot(va[f[0]],np.cross(va[f[i]],va[f[i+1]]))/6 for f in faces for i in range(1,len(f)-1))
        if volume < 0: faces=[list(reversed(f)) for f in faces]
        self.part(name,body,va,faces,color,hardware)

    def box(self, name, body, center, size, color, hardware=False):
        c=np.asarray(center,float); d=np.asarray(size,float)/2
        v=np.array([c+d*np.array([x,y,z]) for z in (-1,1) for y in (-1,1) for x in (-1,1)])
        faces=[[0,2,3,1],[4,5,7,6],[0,1,5,4],[2,6,7,3],[0,4,6,2],[1,3,7,5]]
        self.part(name,body,v,faces,color,hardware)

    def joint(self, name, body, pos, diameter, length):
        p=np.asarray(pos,float)
        self.link(name+"_housing",body,p+[0,-length/2,0],p+[0,length/2,0],
                  [(0,diameter*.42,diameter*.42),(.06,diameter/2,diameter/2),(.94,diameter/2,diameter/2),(1,diameter*.42,diameter*.42)],METAL,True,24)
        for s in (-1,1):
            center=p+[0,s*(length/2+.003),0]
            # Torus on the transverse output face; physical hardware is counted elsewhere.
            v=[]; faces=[]; n,m=24,6; r=diameter*.43; tube=.009
            for i in range(n):
                theta=2*math.pi*i/n
                for j in range(m):
                    phi=2*math.pi*j/m
                    rr=r+tube*math.cos(phi)
                    v.append(center+[rr*math.cos(theta),tube*math.sin(phi),rr*math.sin(theta)])
            for i in range(n):
                for j in range(m): faces.append([i*m+j,((i+1)%n)*m+j,((i+1)%n)*m+(j+1)%m,i*m+(j+1)%m])
            self.part(name+f"_rim_{'left' if s>0 else 'right'}",body,np.asarray(v),faces,GOLD,True)

def build(spec: dict) -> Geometry:
    g=Geometry(spec)
    # A curved, uninterrupted ivory chest wedge; not a humanoid head or a box.
    g.loft("ivory_chest_wedge","torso",[
        ([.40,0,1.77],.036,.07),([.49,0,1.93],.055,.145),
        ([.46,0,2.16],.067,.25),([.30,0,2.40],.075,.36),
        ([.095,0,2.58],.066,.41),([-.045,0,2.65],.042,.335)],IVORY,n=24)
    # AA3 has a gently crowned chest top, rather than a flat chopped rectangle.
    chest=g.parts[-1]
    for vertex in chest['vertices_world_m'][-24:]:
        vertex[2]=round(vertex[2]-.070*(abs(vertex[1])/.335)**2,8)
    g.loft("ivory_back_carapace","torso",[
        ([-.12,0,1.78],.055,.13),([-.29,0,1.94],.071,.31),
        ([-.37,0,2.22],.088,.43),([-.37,0,2.46],.084,.45),
        ([-.27,0,2.59],.065,.38),([-.085,0,2.642],.045,.32)],IVORY,n=24)
    g.loft("torso_internal_carrier_visual","torso",[
        ([.10,0,1.81],.19,.22),([.06,0,2.00],.29,.41),
        ([-.035,0,2.36],.29,.44),([-.04,0,2.50],.16,.39)],DARK,True)
    for side,s in (("left",1),("right",-1)):
        g.loft(side+"_blue_torso_side","torso",[
            ([.34,s*.18,1.87],.10,.077),([.34,s*.25,2.01],.13,.09),
            ([.27,s*.335,2.20],.19,.105),([.055,s*.41,2.40],.235,.105),
            ([-.075,s*.39,2.53],.17,.095)],BLUE,n=24)
        g.loft(side+"_blue_rear_side_transition","torso",[
            ([-.18,s*.25,1.90],.087,.08),([-.22,s*.38,2.15],.13,.082),
            ([-.24,s*.425,2.37],.135,.09),([-.15,s*.39,2.53],.088,.075)],BLUE,n=20)
        g.link(side+"_upper_blue_shoulder_bridge","torso",
            [-.04,s*.39,2.555],[-.12,s*.69,2.41],
            [(0,.090,.065),(.18,.175,.10),(.50,.21,.12),(.82,.17,.105),(1,.10,.08)],BLUE,n=24)
        # Front radiator cassette with a saffron surround and open black slats.
        yc=s*.335
        g.box(side+"_radiator_gold_frame","torso",[.486,yc,2.235],[.038,.145,.325],GOLD)
        g.box(side+"_radiator_dark_face","torso",[.512,yc,2.235],[.008,.105,.285],BLACK,True)
        for i in range(10):
            g.box(side+f"_radiator_louver_{i:02}","torso",[.519,yc,2.108+i*.028],[.009,.089,.009],METAL,True)
    g.box("central_amber_light_rim","torso",[.505,0,2.17],[.038,.060,.215],GOLD)
    g.box("central_amber_light","torso",[.528,0,2.17],[.012,.030,.165],[1,.76,.08,1],True)
    # Back service door lies on the rear carapace, not on a different design.
    g.loft("blue_back_service_panel","torso",[
        ([-.465,0,2.17],.020,.13),([-.471,0,2.20],.022,.155),
        ([-.471,0,2.50],.022,.155),([-.455,0,2.525],.018,.135)],BLUE,square=True)
    g.box("back_service_latch","torso",[-.497,0,2.468],[.012,.07,.025],DARK,True)
    for yy in (-.125,.125):
        for zz in (2.216,2.487):
            g.box(f"back_fastener_{yy}_{zz}".replace('-','n').replace('.','p'),"torso",[-.497,yy,zz],[.012,.018,.018],METAL,True)
    # Compact visible waist, with broad gold pelvis and ivory rear sacral cover.
    g.loft("pelvis_dark_carrier","pelvis",[
        ([.0,0,1.48],.16,.17),([.0,0,1.63],.20,.20),([.0,0,1.76],.18,.18)],DARK,True)
    g.loft("saffron_front_pelvis","pelvis",[
        ([.33,0,1.38],.049,.075),([.36,0,1.42],.057,.105),
        ([.38,0,1.66],.058,.16),([.34,0,1.74],.047,.135)],GOLD,square=True)
    g.box("pelvis_small_black_latch","pelvis",[.423,0,1.437],[.012,.050,.038],DARK,True)
    g.loft("rear_saffron_pelvis_band","pelvis",[
        ([-.20,0,1.56],.043,.29),([-.215,0,1.63],.049,.37),([-.19,0,1.69],.035,.32)],GOLD,square=True)
    g.loft("rear_ivory_sacral_guard","pelvis",[
        ([-.245,0,1.31],.032,.058),([-.25,0,1.37],.036,.085),
        ([-.26,0,1.58],.047,.12),([-.235,0,1.66],.043,.13)],IVORY,square=True)
    for side,s in (("left",1),("right",-1)):
        points={key.removeprefix('left_'): np.array([p[0],s*p[1],p[2]],float)
                for key,p in spec['points_world_m'].items() if key.startswith('left_')}
        sh,el,wr,pa=(points[k] for k in ('shoulder','elbow','wrist','palm'))
        hip,knee,fold,ankle,foot=(points[k] for k in ('hip','knee','fold','ankle','foot'))
        g.joint(side+"_shoulder",side+"_upper_arm",sh,.23,.19)
        g.link(side+"_ivory_upper_arm",side+"_upper_arm",sh,el,
               [(.045,.10,.11),(.18,.17,.145),(.48,.14,.135),(.77,.125,.115),(.88,.087,.093)],IVORY)
        g.loft(side+"_blue_outer_deltoid",side+"_upper_arm",[
            ([-.02,s*.735,2.12],.13,.09),([-.06,s*.755,2.23],.17,.135),
            ([-.12,s*.71,2.38],.155,.135),([-.13,s*.65,2.45],.095,.072)],BLUE)
        g.box(side+"_deltoid_gold_mark",side+"_upper_arm",[.077,s*.874,2.205],[.025,.017,.087],GOLD,True)
        g.joint(side+"_elbow",side+"_forearm",el,.22,.20)
        g.link(side+"_blue_forearm",side+"_forearm",el,wr,
               [(.105,.14,.145),(.20,.195,.167),(.42,.20,.175),(.69,.165,.14),(.91,.12,.098),(.98,.083,.079)],BLUE)
        g.box(side+"_forearm_small_gold_mark",side+"_forearm",[.21,s*.85,1.31],[.018,.04,.07],GOLD,True)
        g.joint(side+"_wrist",side+"_palm",wr,.135,.15)
        g.loft(side+"_ivory_palm",side+"_palm",[
            ([pa[0],pa[1]+s*.020,.975],.083,.12),([pa[0],pa[1]+s*.024,1.025],.099,.125),
            ([pa[0],pa[1]+s*.025,1.135],.089,.12),([pa[0],pa[1]+s*.022,1.174],.062,.095)],IVORY,square=True)
        for i in range(1,4):
            pj=next(j for j in spec['joints'] if j['name']==f'{side}_finger_{i}_proximal')
            dj=next(j for j in spec['joints'] if j['name']==f'{side}_finger_{i}_distal')
            p,d=np.array(pj['position_world_m']),np.array(dj['position_world_m'])
            g.link(f'{side}_finger_{i}_proximal',pj['child'],p,d,
                   [(0,.033,.031),(.18,.039,.034),(.83,.034,.03),(1,.026,.027)],DARK,n=12)
            g.box(f'{side}_finger_{i}_ivory_pad',pj['child'],p+[.036,0,-.043],[.018,.060,.061],IVORY)
            end=d+[.060,-s*.029,-.059]
            g.link(f'{side}_finger_{i}_distal',dj['child'],d,end,
                   [(0,.027,.028),(.18,.034,.032),(.58,.031,.029),(1,.023,.024)],DARK,n=12)
        pj=next(j for j in spec['joints'] if j['name']==side+'_thumb_proximal')
        dj=next(j for j in spec['joints'] if j['name']==side+'_thumb_distal')
        p,d=np.array(pj['position_world_m']),np.array(dj['position_world_m'])
        g.box(side+'_thumb_pivot_web',side+'_palm',[.07,s*.665,1.116],
              [.075,.13,.045],DARK,True)
        g.link(side+'_thumb_proximal',pj['child'],p,d,[(0,.035,.035),(.2,.045,.039),(.8,.038,.034),(1,.027,.027)],DARK,n=12)
        g.link(side+'_thumb_distal',dj['child'],d,d+[.063,-s*.038,-.058],[(0,.027,.027),(.2,.031,.028),(.85,.028,.025),(1,.021,.021)],DARK,n=12)
        g.joint(side+"_hip",side+"_thigh",hip,.29,.24)
        g.loft(side+"_ivory_hip_transition_cuff",side+"_thigh",[
            ([.018,s*.37,1.59],.042,.081),([.027,s*.365,1.65],.055,.095),
            ([.020,s*.34,1.72],.052,.085),([.01,s*.31,1.747],.034,.05)],IVORY,n=16)
        g.link(side+"_blue_thigh",side+"_thigh",hip+[.055,0,-.012],knee+[.035,0,.045],
               [(.09,.14,.145),(.26,.22,.205),(.52,.215,.20),(.78,.175,.163),(.94,.126,.12)],BLUE)
        g.loft(side+"_orange_knee_guard",side+"_thigh",[
            ([.39,s*.424,1.013],.049,.10),([.43,s*.418,1.075],.060,.145),
            ([.37,s*.41,1.245],.053,.155),([.33,s*.407,1.29],.042,.118)],GOLD,square=True)
        g.joint(side+"_knee",side+"_middle_shank",knee,.29,.245)
        g.link(side+"_blue_middle_shank",side+"_middle_shank",knee+[.05,0,-.01],fold+[.04,0,.028],
               [(.15,.155,.15),(.28,.19,.18),(.5,.175,.165),(.8,.125,.125),(.91,.09,.10)],BLUE)
        g.joint(side+"_fold",side+"_distal_shank",fold,.22,.215)
        g.link(side+"_gray_distal_carrier",side+"_distal_shank",fold,ankle,
               [(.11,.079,.089),(.28,.095,.10),(.74,.085,.09),(.89,.059,.071)],METAL,True)
        g.loft(side+"_blue_distal_front_guard",side+"_distal_shank",[
            ([.055,s*.52,.31],.026,.07),([.06,s*.515,.345],.032,.10),
            ([.045,s*.502,.45],.036,.102),([.023,s*.498,.476],.025,.071)],BLUE,square=True)
        g.joint(side+"_ankle",side+"_foot",ankle,.205,.205)
        fx,fy,fz=foot
        g.loft(side+"_dark_sole",side+"_foot",[
            ([fx,fy,0],.433,.288),([fx,fy,.021],.45,.305),
            ([fx,fy,.043],.447,.302),([fx,fy,.05],.42,.28)],DARK,square=True)
        g.loft(side+"_ivory_foot_upper",side+"_foot",[
            ([fx+.025,fy,.049],.417,.283),([fx+.01,fy,.084],.408,.274),
            ([fx-.055,fy,.15],.285,.205),([fx-.085,fy,.18],.21,.16)],IVORY,square=True)
        g.loft(side+"_dark_rear_heel",side+"_foot",[
            ([fx-.325,fy,.044],.121,.259),([fx-.31,fy,.075],.125,.255),
            ([fx-.285,fy,.167],.095,.209),([fx-.28,fy,.175],.087,.198)],DARK,square=True)
        g.loft(side+"_ivory_ankle_inst_ep",side+"_foot",[
            ([fx-.1,fy,.135],.12,.148),([fx-.14,fy,.22],.092,.129),
            ([fx-.18,fy,.244],.075,.10)],IVORY,square=True)
    return g

def main():
    p=argparse.ArgumentParser(description=__doc__)
    p.add_argument('--spec',type=Path,default=ROBOT/'configs/layout_b_spec.json')
    p.add_argument('--output',type=Path,default=ROBOT/'cad/source/layout_b_scene.json')
    args=p.parse_args()
    spec=json.loads(args.spec.read_text())
    image=ROBOT/spec['appearance_authority']['path']
    assert sha(image)==spec['appearance_authority']['sha256']
    g=build(spec)
    allv=np.concatenate([np.array(part['vertices_world_m']) for part in g.parts])
    scene={
        'schema':'gorilla_layout_scene_v1','robot_id':spec['robot_id'],
        'checkpoint_id':spec['checkpoint_id'],'spec_sha256':sha(args.spec),
        'image_sha256':sha(image),'spec_path':str(args.spec.relative_to(ROOT)),
        'appearance_authority_path':str(image.relative_to(ROOT)),
        'units':'m','coordinate_frame':spec['coordinate_frame'],
        'rgba_encoding':'sRGB colors; renderer converts to linear shader inputs',
        'parts':g.parts,'bounds_world_m':[allv.min(axis=0).tolist(),allv.max(axis=0).tolist()],
        'dimensions_xyz_m':np.ptp(allv,axis=0).tolist(),
        'appearance_status':'candidate_requires_actual_four_view_review',
        'source_uncertainties':['Artwork cameras are not calibrated orthographic views.',
            'Hidden joint axis depths and armor curvature are reconstructed estimates.',
            'Closed single-surface panels are not modeled inner/outer manufacturing walls.',
            'Decorative hardware repeats independently counted module/frame mass.'],
    }
    args.output.parent.mkdir(parents=True,exist_ok=True)
    args.output.write_text(json.dumps(scene,indent=2)+'\n')
    export=ROBOT/'cad/exports/layout_b'; export.mkdir(parents=True,exist_ok=True)
    obj=[];mtl=[];offset=1
    for part in g.parts:
        obj.extend(['o '+part['name'],'usemtl '+part['name']])
        obj.extend('v '+' '.join(map(str,v)) for v in part['vertices_world_m'])
        obj.extend('f '+' '.join(str(i+offset) for i in face) for face in part['faces'])
        mtl.extend(['newmtl '+part['name'],'Kd '+' '.join(map(str,part['rgba'][:3])),'Ns 30'])
        offset+=len(part['vertices_world_m'])
    (export/'layout_b.obj').write_text('mtllib layout_b.mtl\n'+'\n'.join(obj)+'\n')
    (export/'layout_b.mtl').write_text('\n'.join(mtl)+'\n')
    print(json.dumps({'scene':str(args.output),'parts':len(g.parts),'dimensions_xyz_m':scene['dimensions_xyz_m']}))

if __name__=='__main__': main()

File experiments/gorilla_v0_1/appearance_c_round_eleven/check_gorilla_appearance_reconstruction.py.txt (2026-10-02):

#!/usr/bin/env python3
"""Check C source/render/export identity and mesh integrity, never beauty."""
from __future__ import annotations

import argparse
import hashlib
import json
from pathlib import Path

import numpy as np
import trimesh

ROOT=Path(__file__).resolve().parents[2]
ROBOT=ROOT/"robots/gorilla_v0_1"

def sha(p):return hashlib.sha256(p.read_bytes()).hexdigest()

def main():
    p=argparse.ArgumentParser(description=__doc__)
    p.add_argument("--scene",type=Path,default=ROBOT/"cad/source/appearance_c_scene.json")
    p.add_argument("--render",type=Path,default=ROBOT/"cad/exports/appearance_c/appearance_c_render_manifest.json")
    p.add_argument("--output",type=Path,default=ROBOT/"evidence/appearance_c_resource_check.json")
    args=p.parse_args();source=json.loads(args.scene.read_text());render=json.loads(args.render.read_text())
    errors=[];control_bad=[];export_bad=[]
    bindings=[*source["build_inputs"],{"path":source["spec_path"],"sha256":source["spec_sha256"]},
              {"path":source["appearance_authority_path"],"sha256":source["image_sha256"]},
              {"path":render["renderer_script_path"],"sha256":render["renderer_script_sha256"]},
              *render["images"],*render.get("exports",[])]
    for b in bindings:
        f=ROOT/b["path"]
        if not f.is_file() or sha(f)!=b["sha256"]:errors.append("Changed/missing bound file: "+b["path"])
    if render["scene_sha256"]!=sha(args.scene):errors.append("Render belongs to a different scene")
    for k in ("spec_sha256","image_authority_sha256"):
        expected=source["spec_sha256" if k=="spec_sha256" else "image_sha256"]
        if render[k]!=expected:errors.append("Identity mismatch: "+k)
    groups={}
    for part in source["parts"]:
        faces=[[f[0],f[i],f[i+1]] for f in part["faces"] for i in range(1,len(f)-1)]
        m=trimesh.Trimesh(vertices=part["vertices_world_m"],faces=faces,process=False)
        if not(m.is_watertight and m.is_winding_consistent and m.volume>0):control_bad.append(part["name"])
        if part.get("physical_mass_assigned") is not False:errors.append("Unexpected physical mass claim: "+part["name"])
        if part.get("surface_projection_unresolved_vertices",0):errors.append("Unattached surface detail: "+part["name"])
        groups[part["name"]+"_mesh"]=[]
    glb=ROBOT/"cad/exports/appearance_c/appearance_c.glb"
    loaded=trimesh.load(glb,force="scene")
    unassigned=[]
    for name,m in loaded.geometry.items():
        if name in groups:groups[name].append(m)
        else:
            matches=[k for k in groups if name.startswith(k+"_")]
            if len(matches)==1:groups[matches[0]].append(m)
            else:unassigned.append(name)
    for name,meshes in groups.items():
        if not meshes:export_bad.append({"part":name,"problem":"missing"});continue
        m=trimesh.util.concatenate(meshes)
        # Material/normal seams split vertices in glTF; topology is evaluated
        # after positional welding. Geometry coordinates are not modified.
        m.merge_vertices(merge_tex=True,merge_norm=True)
        if not(m.is_watertight and m.is_winding_consistent and m.volume>0):
            export_bad.append({"part":name,"closed":m.is_watertight,"winding_consistent":m.is_winding_consistent,"signed_volume_m3":float(m.volume)})
    if unassigned:errors.append("Unexpected GLB mesh primitives: "+str(unassigned))
    # Blender glTF Y-up: world (X,Y,Z) -> glTF (X,Z,-Y).
    lo,hi=np.asarray(source["bounds_world_m"])
    expected=np.array([[lo[0],lo[2],-hi[1]],[hi[0],hi[2],-lo[1]]])
    bound_error=float(np.abs(loaded.bounds-expected).max())
    if bound_error>2e-5:errors.append("GLB bound difference exceeds 20 micrometres")
    if source["appearance_accepted"] or render["appearance_accepted"]:errors.append("This checker cannot authorize appearance acceptance")
    if source["physics_accepted"] or render["physics_accepted"]:errors.append("Appearance assets cannot authorize physical acceptance")
    passed=not(errors or control_bad or export_bad)
    report={"schema":"gorilla_appearance_resource_check_v1","checkpoint_id":"gorilla_appearance_c",
        "scene_sha256":sha(args.scene),"render_manifest_sha256":sha(args.render),"glb_sha256":sha(glb),
        "checker_path":str(Path(__file__).resolve().relative_to(ROOT)),"checker_sha256":sha(Path(__file__).resolve()),
        "scope":"Input/file identities, closed oriented control surfaces and actual exported part surfaces. Does not judge shape fidelity, manufacture, collision, mass or dynamics.",
        "mesh_vertices_note":"Export normals/materials split vertices; positional welding is used solely for topology inspection. Multi-material primitives are combined by original named source part.",
        "control_part_count":len(source["parts"]),"export_material_primitive_count":len(loaded.geometry),
        "glb_bound_max_abs_difference_m":bound_error,"binding_errors":errors,"control_mesh_failures":control_bad,"export_mesh_failures":export_bad,
        "render_assets_valid":passed,"appearance_accepted":False,"physics_accepted":False}
    args.output.parent.mkdir(parents=True,exist_ok=True);args.output.write_text(json.dumps(report,indent=2)+"\n")
    print(json.dumps(report));raise SystemExit(0 if passed else 1)

if __name__=="__main__":main()

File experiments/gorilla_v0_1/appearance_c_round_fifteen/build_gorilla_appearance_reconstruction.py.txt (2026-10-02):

#!/usr/bin/env python3
"""Reconstruct the sole Gorilla AA3 artwork as editable hard-surface geometry.

This appearance source has no physical approval or inferred hardware mass.
Pixel coordinates refer to the user's original 1280-square sheet; hidden depths
are explicit reconstruction choices, not measurements from calibrated cameras.
"""
from __future__ import annotations

import argparse
import hashlib
import json
import math
from pathlib import Path

import numpy as np
from scipy.interpolate import PchipInterpolator

from build_gorilla_proportion_layout import Geometry as PrimitiveGeometry

ROOT = Path(__file__).resolve().parents[2]
ROBOT = ROOT / "robots/gorilla_v0_1"
SCALE = 2.65 / 516
CX = 325.5
GROUND = 603
PALETTE = {
    "ivory": [0.91, 0.88, 0.80, 1],
    "blue": [0.015, 0.57, 0.88, 1],
    "gold": [1.0, 0.64, 0.13, 1],
    "dark": [0.075, 0.08, 0.084, 1],
    "metal": [0.16, 0.17, 0.17, 1],
    "black": [0.018, 0.022, 0.026, 1],
}
IVORY, BLUE, GOLD, DARK, METAL, BLACK = (PALETTE[k] for k in ("ivory", "blue", "gold", "dark", "metal", "black"))

def sha(path: Path) -> str:
    return hashlib.sha256(path.read_bytes()).hexdigest()

def yz(px, py, rear=False):
    return np.array([(px - CX if rear else CX - px) * SCALE, (GROUND - py) * SCALE])

class Geometry(PrimitiveGeometry):
    """A named control mesh plus explicit surface finish parameters."""

    def part(self, name, body, vertices, faces, color, hardware=False, note=""):
        super().part(name, body, vertices, faces, color, hardware, note)
        part = self.parts[-1]
        part.pop("shell_density_kg_m3")
        part.pop("shell_thickness_m")
        part.pop("mass_basis_note")
        part.update({
            "role": "visible_mechanism" if hardware else "armor_surface",
            "physical_mass_assigned": False,
            "reconstruction_note": note or "Visible shape reconstructed from the sole artwork; hidden depth is a candidate.",
            "edge_bevel_m": 0,
            "bevel_segments": 3,
            "surface_shading": "mechanical_smooth" if hardware else "flat_weighted_normals",
        })

    def cover(self,name,body,vertices,surface_faces,color,thickness=.007,
              reference_closed_faces=None,sharp_outer_edges=None,note=""):
        """A hollow armor cover: outer skin, inner skin and boundary returns.
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

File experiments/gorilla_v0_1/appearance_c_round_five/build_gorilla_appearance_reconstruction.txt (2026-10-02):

#!/usr/bin/env python3
"""Reconstruct the sole Gorilla AA3 artwork as editable hard-surface geometry.

This appearance source has no physical approval or inferred hardware mass.
Pixel coordinates refer to the user's original 1280-square sheet; hidden depths
are explicit reconstruction choices, not measurements from calibrated cameras.
"""
from __future__ import annotations

import argparse
import hashlib
import json
import math
from pathlib import Path

import numpy as np
from scipy.interpolate import PchipInterpolator

from build_gorilla_proportion_layout import Geometry as PrimitiveGeometry
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

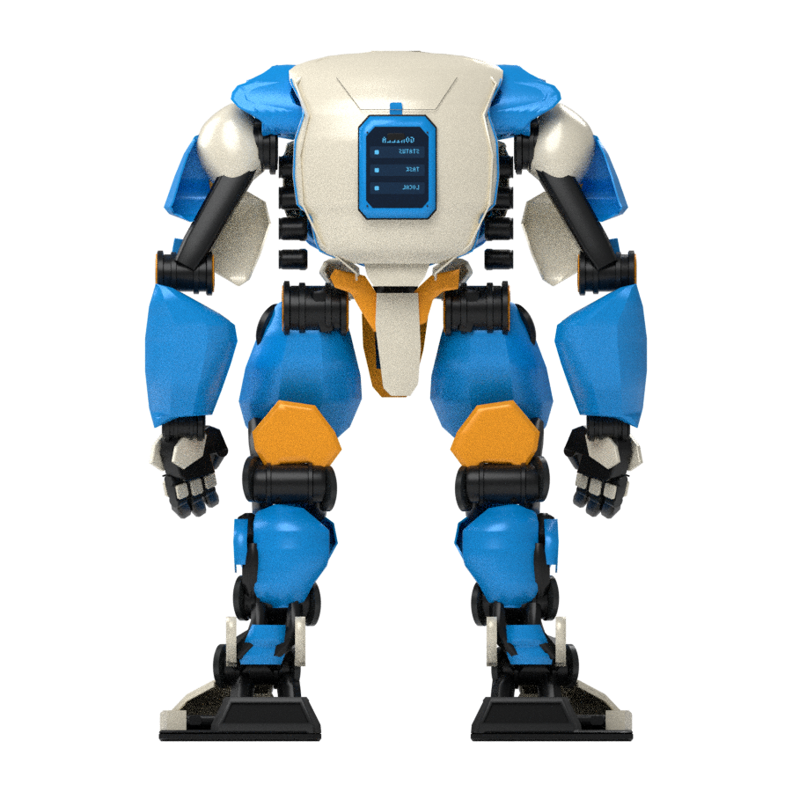
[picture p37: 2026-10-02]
robots/gorilla_v0_1/images/appearance_c_c13_assembly_screen_probe_rear.png

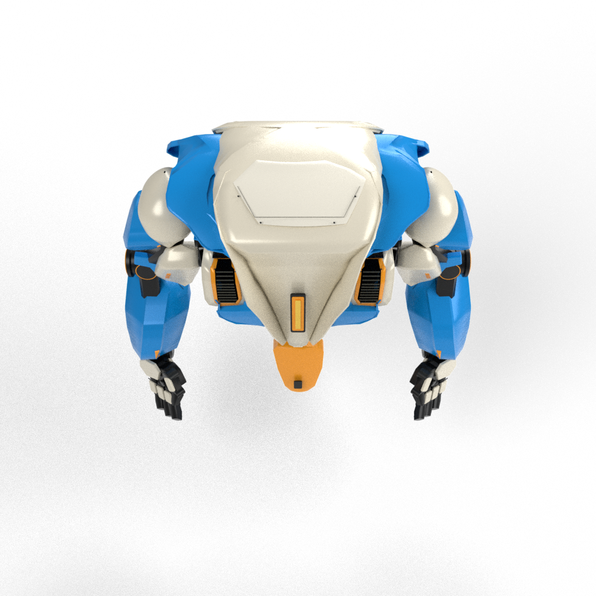
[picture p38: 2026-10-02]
robots/gorilla_v0_1/images/appearance_c_top_upper_assembly.png

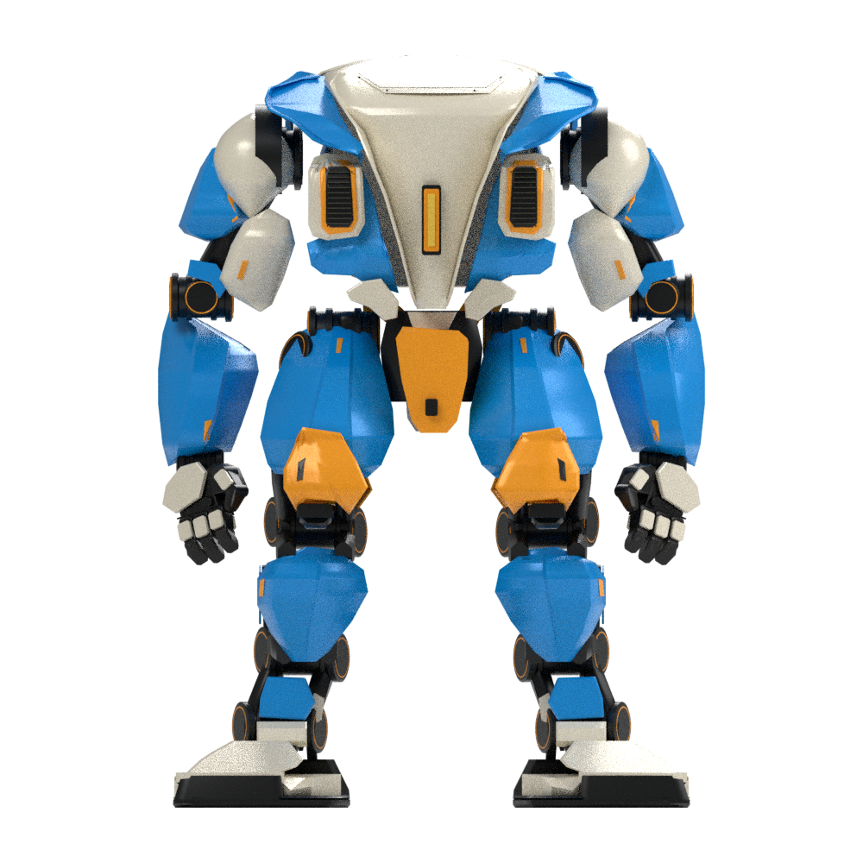
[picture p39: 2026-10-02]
robots/gorilla_v0_1/images/appearance_c_c13_shoulder_assembly_probe_front.png

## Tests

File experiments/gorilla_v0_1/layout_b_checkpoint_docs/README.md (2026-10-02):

# Gorilla V0.1

当前检查点：**`gorilla_layout_b`，按原图比例的探索工程布局，尚未冻结**。本轮从用户交接的 AA3 外观建立同源三维布局、质量账本、物理筛查和下一阶段入口。

唯一当前状态入口：[当前决定与门禁](design/current_decisions.md)。

| 资料 | 入口 |
|---|---|
| 唯一外观基准 | [用户再次确认的四视图](design/concepts/aa3/user_confirmed_four_view.jpg)；其他图片与粗模仅为历史资料 |
| 来源身份 | [唯一外观权威记录](source/appearance_authority.json)；[原包导入与哈希](source/appearance_import.json) |
| 当前布局参数源 | [layout_b_spec.json](configs/layout_b_spec.json)；[首轮候选评审与复现入口](design/layout_b_checkpoint_review.md) |
| 实际三维布局 | [四视图](images/layout_b_four_view.png)、[Blender 源](cad/source/layout_b.blend)、[GLB](cad/exports/layout_b/layout_b.glb)；简化代理，外观未放行 |
| 工程证据 | [SI 合同](models/full/robot.json)、[汇总](evidence/layout_b_checkpoint.json)、[质量账本](hardware/layout_b_mass_components.csv)、[静力与拒绝测试](evidence/layout_b_screen.json) |
| 历史尺寸探索参数 | [layout_a_spec.json](configs/layout_a_spec.json)；未生成模型，不能作为外观基准 |
| 任务与接口边界 | [任务和仿真交接](design/task_and_simulation_handoff.md) |
| 器件依据 | [驱动和供电参照](hardware/component_basis.md) |

首版核心为双足移动、双手操作、自主感知/规划/执行，最终在 Bevy 等游戏引擎的原生物理世界中完成搬运和环境操作。GD01 用于大型机器人方向参考；Goose 用于流程经验。两者的轴数、质量、尺寸、执行器和策略不继承。

首轮候选已生成，但首个检查点尚未达标：内部装配、空载静力、关键动作和外观仍未放行。三维布局、静力力代理和短时加载验证各有不同证据范围。此候选不能宣称已实现自主任务、持续驱动能力或制造放行。

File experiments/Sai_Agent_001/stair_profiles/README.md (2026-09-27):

# Experimental 60 mm profiles

These are development profiles, not replacements for `stairs-dev40` and were not part of
the alpha.2 release. The original two ONNX files are exported from GPU trials
008 and 006. The additional `descent60-trial010` actor is a new five-minute GPU
trial. Each JSON retains its own training metadata and actor hash.

| Case | Articulated MuJoCo | Godot/Jolt |
|---|---|---|
| Ascent, trial 008 | Completes in 33.38 s including final stop, under an explicit 45 s diagnostic budget; original 30 s test still fails | Completes in 27.18 s with motion-relative phase |
| Descent, trial 006 with half crouch and route steering | Completes in 15.46 s | Fails lane containment: maximum lateral displacement 0.658 m |

Both use a fixed four-riser flight, 60 mm risers, 180 mm treads and no payload.
These are tuning cases, not held-out terrain. Success requires every wheel to
clear, three seconds stopped, final height, support, uprightness and a 0.3 m
centerline corridor. Failed attempts remain in
[the complete diagnostic record](../../../robots/Sai_Agent_001/evidence/stairs-60-diagnostics.json).

From a source checkout, run the actual Godot ascent experiment:

```sh
uv run sai-agent godot --stairs .06 --stair-profile experiments/Sai_Agent_001/stair_profiles/ascent60.json
```

The descent profile can be reproduced with `--descending` and
`experiments/Sai_Agent_001/stair_profiles/descent60.json`; it currently fails acceptance.
The profiles remain in the source experiments directory, outside the bundled
wheel assets. The default CLI continues to use the accepted flat/20–40 mm
actors unless a profile is explicitly selected.

The descent controller requests half crouch and a heading toward the known
straight route at world y=0. Steering modifies wheel speeds; it never moves
the base or feet directly. This uses simulated odometry, not a demonstrated
camera/VLA localization pipeline. A/D overrides route steering while held.

Experimental gait phase starts at 0.5 seconds of the reference cycle when
forward motion begins, independent of when W is pressed. This aligns the
initial phase with the CPU diagnostic. It improved the Godot descent from a
fall to a lane failure; it did not make that case pass. No physics parameters,
motor limits, robot geometry or acceptance corridor were changed.

## Crouched descent training: trial 010

Trial 010 starts from checkpoint 006 and trains the deployed half-crouch plus
known-route steering, with a 0.6 rad/s heading correction bound. It completed
5,849,088 steps in 300.29 seconds on GB10 with two CPU threads. ONNX parity
passed at batches 1, 17 and 256, maximum absolute difference 1.91e-6.

At 0.08 m/s the full articulated MuJoCo suite passes 15/15 and Godot passes
14/15: three riser heights (20/40/60 mm), nominal 180 mm tread/yaw zero and
160/200 mm treads with initial yaw ±0.08 rad. The failed Godot case is 60 mm,
160 mm tread, +0.08 rad. It loses support before the three-second stop starts.
Reducing swing lift from 55 to 30 mm also fails. Reducing speed to 0.06 m/s
fixes that start angle but fails the opposite angle; its Godot total is again
14/15. Neither tuning change is promoted. These are now development regression
cases, not untouched holdouts. All original results remain in
[the trial record](../../../robots/Sai_Agent_001/evidence/stairs-010-crouched-descent.json).

```sh
uv run sai-agent godot --stairs .06 --descending --stair-profile experiments/Sai_Agent_001/stair_profiles/descent60-trial010.json
```

For the failing variation add `--stair-tread .16 --initial-yaw .08`. A recorded
run additionally uses `--headless --case W --duration 45 --output artifacts/run.json`.
The renderer, sensors, full articulation and motors run normally; yaw is applied
only to the complete initial state before the first physics tick.

## Placement variation training: trial 011 / packaged descent60

Trial 011 continues from 010, changes the training tread to 160 mm, and samples
initial yaw within ±0.12 rad and start distance within ±80 mm. It completed
5,816,320 steps in 300.39 seconds on GB10, with two CPU threads. Robot geometry,
actuator torque limits and acceptance criteria are unchanged.

At the trained 0.08 m/s command, **all 15 full-MuJoCo and all 15 Godot descent
regressions pass**, including both previously failing narrow-tread start
angles. Nominal 60 mm Godot descent completes in 16.48 simulated seconds. The
cases have been used in development, so they are not described as untouched
holdouts. No loaded stairs or camera-based terrain reconstruction is claimed.
See [complete results](../../../robots/Sai_Agent_001/evidence/stairs-011-descent-placement.json).

Alpha.3 bundles this actor as `--stair-skill descent60`, with matching crouch,
phase and route-steering settings. `--stair-skill ascent60` bundles trial 008
and its earlier nominal-course result. Both remain explicit experimental
options; `stairs-dev40` remains the default. Trial 010 and its failed controller
diagnostics remain available for reproducibility.

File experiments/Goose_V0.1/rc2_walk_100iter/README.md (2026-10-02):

# RC2 旧控制契约步态试验（保留失败样本）

本目录保存 `goose_rc2_v1` 的 100 轮 RSL PPO 训练检查点、ONNX 策略、元数据与配置。8 个环境、每轮 32 步，共 25,600 个环境步；模型 SHA-256 `07d4209a5a7b9322a04b9cdb62694a69cf35c97716c262909d21f039599c4cb0`。策略只作失败复现，**不得部署**。

[独立回放](../../../robots/Goose_V0.1/evidence/walk_policy_100iter_rc2.json)的静止、前进、后退、左转四项均在约 1.5–1.94 秒跌倒，没有交替离地。随后确认旧环境从未通过站立测试的 `home` 姿态重置，旧动作目标范围无法达到已验证的膝关节站姿角度；[直腿姿态失败记录](../../../robots/Goose_V0.1/evidence/stand_home_failure_rc2.json)保留。后续控制契约升级到 `goose_rc2_v2`，以中立文件的具名 `standing` 作为动作目标基准，并重新测试 Godot/Jolt 站立；此目录不是新版本策略。

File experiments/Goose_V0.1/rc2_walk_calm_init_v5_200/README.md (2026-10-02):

# RC2 低探索、零动作起步的 v5 步态对照（失败样本）

与 `rc2_walk_neutral_v5_200` 使用相同模型、规格、SI 控制契约、奖励和 51,200 环境步；本试验把初始 Gaussian 动作标准差从 0.22 降为 0.05，并把策略输出层初始化为零。检查点、ONNX、元数据和 runner 配置来自同一次 200 轮训练；元数据保存修改后的源码哈希、初始化参数和策略哈希。

[固定种子探索探针](../../../robots/Goose_V0.1/evidence/policy_exploration_probe_rc2.json)只是选择该对照的局部依据，不是鲁棒安全阈值。训练期失败次数由原 v5 的 877 降为 255，但[MuJoCo 独立自由机身回放](../../../robots/Goose_V0.1/evidence/walk_policy_calm_init_v5_200_rc2.json)静止、前进、后退和左转仍分别在 2.80、2.92、2.78 和 4.16 秒跌倒，四项都没有双脚真实离地。[Godot/Jolt 同策略静止诊断](../../../robots/Goose_V0.1/evidence/godot_jolt_policy_calm_init_v5_200_diagnostic_rc2.json)虽未摔倒，具名站姿判据仍失败；这不是跨引擎步行验收。初始前进指令的动作变化量也很小；尚未学到可验收的速度响应。不能部署或拿训练奖励替代步行验收。

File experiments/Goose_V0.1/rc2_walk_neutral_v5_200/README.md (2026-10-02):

# RC2 真实 5 ms 站姿控制下的 v5 步态试验（失败样本）

本目录保留 `goose_rc2_v5` 的 200 轮 RSL PPO 候选：8 个环境、每轮 32 步，共 51,200 环境步。训练与运行共用中立重力前馈、20 ms 策略及 5 ms 力矩周期，腿部阻尼为 0.10；ONNX 导出与训练网络数值一致。`checkpoint.pt`、`policy.onnx`、`metadata.json`、`runner_config.json` 属同一次试验。

[无策略的自由站立](../../../robots/Goose_V0.1/evidence/stand_neutral_policy_mode_v5_8s_rc2.json)可持续 8 秒，但[原策略独立回放](../../../robots/Goose_V0.1/evidence/walk_policy_200iter_v5_rc2.json)的静止、前进、后退、左转都在 0.98–1.34 秒跌倒；[Jolt 同一候选的静止策略回放](../../../robots/Goose_V0.1/evidence/godot_jolt_policy_v5_diagnostic_rc2.json)也失稳。作为诊断，将动作乘以 0.25 后[静止可完成 8 秒](../../../robots/Goose_V0.1/evidence/walk_policy_v5_scaled_diagnostic_rc2.json)，其余三项没有实际抬脚、前后行走或正确转向。动作缩放不是版本化策略修复，也不得部署。下一轮应先解决稳定动作和指令响应，再训练与跨引擎回放；不无限追加轮数。

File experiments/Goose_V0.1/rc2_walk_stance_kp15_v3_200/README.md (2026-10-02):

# RC2 高增益、模型内部前馈步态试验（失败样本）

本目录保留 `goose_rc2_v3` 的 200 轮 RSL PPO 候选：8 个环境、每轮 32 步，共 51,200 环境步。`checkpoint.pt`、`policy.onnx`、`metadata.json` 与 `runner_config.json` 是同一次训练输出；模型和规格 SHA 见元数据。

此版训练每个扭矩周期使用 MuJoCo 内部 `qfrc_bias`，运行接收器则只能从引擎中立刚体包计算重力前馈。[仅作失配诊断的回放](../../../robots/Goose_V0.1/evidence/walk_policy_v3_on_v4_receiver_rc2.json)把该策略注入当前中立 MuJoCo 接收器，静止、前进、后退、左转都约 1 秒跌倒。诊断特意绕过版本护栏；正常运行应拒绝 v3 策略。不能把这份结果当作原 v3 训练环境回放，也不能部署。后续 v4 重新使用与运行时一致的前馈训练。

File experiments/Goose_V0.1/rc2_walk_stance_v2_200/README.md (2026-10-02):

# RC2 站姿基准、低增益步态试验（保留失败样本）

本目录保存 `goose_rc2_v2` 的 200 轮 RSL PPO 训练检查点、ONNX 策略、元数据与配置。8 个环境、每轮 32 步，共 51,200 环境步。相比 v1，本试验已让训练起姿和动作中心统一为具名 `standing`，腿部位置增益仍为 5 N·m/rad。

[独立回放](../../../robots/Goose_V0.1/evidence/walk_policy_200iter_v2_rc2.json)的静止、前进、后退、左转仍均在约 1.7–2.0 秒跌倒，没有脚部离地。对照静态试验发现同一模型只用重力前馈时低增益站姿也不稳定；后续 `goose_rc2_v3` 改用经过 MuJoCo 与 Godot/Jolt 独立 4 秒站立复测的腿部增益。此 v2 策略只供失败复现，**不得部署**。

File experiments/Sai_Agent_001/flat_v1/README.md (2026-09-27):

# Flat v1 reproduction checkpoint

This is the preserved training checkpoint for the deployed flat actor, moved
from `policies/flat-v1.pt` without changing its bytes. It is a selected
reproduction input, not a new candidate or part of the runtime wheel.

The deployed [ONNX actor](../../../shared/policies/flat-v1.onnx) and
[metadata](../../../shared/policies/flat-v1.json) remain shared by 001/002.
The metadata retains the checkpoint SHA-256 and original training record.

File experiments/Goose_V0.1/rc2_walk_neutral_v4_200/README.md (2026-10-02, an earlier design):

# RC2 中立前馈步态 v4（失败样本）

200 轮、8 环境、每轮 32 步，共 51,200 环境步；策略观测 53 维，输出 10 维。训练和运行都使用中立刚体重力前馈，ONNX 与训练网络数值一致。

[独立回放](../../../robots/Goose_V0.1/evidence/walk_policy_200iter_v4_rc2.json)的静止、前进、后退、左转均在 0.94–1.22 秒失稳。诊断发现最初标作“普通策略站立”的[旧 1 ms 试验](../../../robots/Goose_V0.1/evidence/stand_neutral_continuous_torque_v4_rc2.json)没有按控制契约的 5 ms 更新力矩；[修正后的 5 ms 试验](../../../robots/Goose_V0.1/evidence/stand_neutral_policy_mode_v4_rc2.json)亦失稳。这个 v4 策略不得部署；v5 改变腿部阻尼并重新做两引擎站立与训练。

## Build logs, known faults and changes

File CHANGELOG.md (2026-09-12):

# Changelog

## 0.1.0a2 — simulation preview

- Packaged the physical 100 g SO101 pickup, cargo securing and loaded crawl task
  with public assets and no object attachments. MuJoCo and Godot pass 18/25 mm
  obstacle courses and no-clamp negative controls.
- Added R restart for the entire Godot scene/controller and fixed the observed
  visible-window VSync throttle without changing physics.
- Retained the validated WASD/held-Shift flat actor and 20/40 mm stair actor.
  Trials 006–009 did not replace them; 60 mm remains unpassed. Raw full-model
  tread/yaw holdouts passed 14/16. A paired check with the already deployed
  heading layer passed 15/16; one descent still leaves the lateral corridor.
- Updated the existing Godot project's optional profile; fresh GitHub install
  and cargo launch pass, alongside 38 original MD input tests.
- Added Ubuntu x86 CI for installation, physical regressions and wheel build.
  Included front/rear CAD-constrained material studies and actual game views.
- Unity asset setup and the portable C# contract have passing checks in draft
  PR #3. Actual editor/runtime and Unity stair/cargo acceptance remain pending.

Hardware manufacture, measured physical parameters, touchscreen firmware and
camera-based VLA are not part of this simulation preview's validated scope.

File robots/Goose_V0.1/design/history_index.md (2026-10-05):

# 历史记录与阶段候选

本页保存截至2026-10-04、提交`07393e882`的旧首页记录，供设计追溯。其“当前／最新／默认”表述属于各自检查点，不是现行交付入口。原图片、采购表、成功与失败证据保留原路径和版本。

**找当前交付，请返回[Goose首页](../README.md)。** 优化后的碰撞示意图和碰撞文件已直接列在首页；无需从以下历史记录查找。

---

# Goose V0.1

**当前碰撞交付（2026-10-04）：[11 叶 Sim2Sim 工程入口](task_proxy_11_v1.md)已通过 M0 验收。** [唯一入口](../configs/task_proxy_11_v1_entry.json)绑定同版模型、契约与原生接收器；硬件源未改，源／目标各完成 2,500 次实际积分，并通过有限 FK、已知危险组合、惯量、时钟与摩擦测试。该入口可交 Sai_Lab 绑定新策略；学会行走、起身、拾取／拖拽、复杂地面、其他引擎及完整制造仍各自验收。旧 30,105 叶和 89 叶失败版本保留为历史，以下较早“默认／最新”均属于各自检查点。

**当前优先级：先跑通虚拟侧。** [本周期训练冻结及直接交接](virtual_training_freeze_handoff.md)固定004包和10.430690821kg完整SI，不等待PCB、采购及制造收尾；Lab独立物理／GPU准入通过后开展训练。后续硬件候选与虚拟版的逐体参数差异已明确记录，没有静默改入训练版。

[指定物虚拟输入v1](task_samples_v1_handoff.md)一次交付圆柱抓杆／把手两家族×100／200／300g的几何、完整SI、外部凸体和实际示意图。320个有限地面组合中35个实际样件端点及三档理想静力筛查通过；把手使用嘴垫前移30mm的参考位置，原中部抓点的配重箱碰撞反例保留。局部接触台架仍有穿透／速度超限，完整拾取和接触质量未放行；本批不改变004或等待采购。

[倒地接触诊断](source_contact_domain_diagnostic.md)已在004原样CPU源完成14个初态、1,400次有限积分及最差初态的100步精确回放。前倾首次头部触地仍出现最大37.21mm瞬态穿地，故站立M0不覆盖翻倒／起身；具体输入已交Lab，站立／移动主线继续。

碰撞范围与参考：[现行对照与范围](../configs/game_collision_budget_v1.json)、[MicroDuck 双足游戏包计数核对](../evidence/microduck_game_collision_baseline_v1.json)、[MD/G1 接触角色与精度对照](simulation_collision_reference_review.md)。29 是用户澄清的随手数字，MD 的 11 个是具体参考版本实数；新版以任务接触、实际目标后端及动态测试共同验收。原 512 目标与 30,105 块源参考均不作为游戏交付。硬件源与完整 SI 参数保留；本版足底采用独立的平地整体接触近似，未继承真实多区 TPU 的材料和复杂地面资格。

相邻凸包可在连接处交错；[有效过滤表](../configs/task_proxy_11_v1_collision_filter.json)只忽略同机内 9 组连接处配对，其余 46 组自碰保留，包括头与身体、左右脚。地面、物品与其他机器人接触均保留；[逐对实测](../evidence/task_proxy_11_v1_collision_filter_acceptance.json)在 MuJoCo 和原生 Rapier 各通过 97 个刻意重叠夹具。真实 CAD 装配干涉单独检查，代理例外不放行制造。

[Godot/Jolt过滤实测](../evidence/task_proxy_11_v1_godot_filter_acceptance.json)另外通过152个原生夹具（同样97个配对／外部接触检查，另加55个未过滤阳性对照），并验证实例重新应用、错误排除拒绝和关节默认屏蔽复位。新接收工具逐对应用有效表，不沿用旧接收器的全部关节自动排除。这里只验收独立形状／过滤夹具，Jolt整机动力学仍未放行；[Godot自带物理后端的深重叠失败](../evidence/godot_physics_collision_filter_rejection.json)保留，未混入Jolt通过结论。

当前独立整机结构：[手动翼形检修门检查点](manual_wing_service_checkpoint.md)。478显示对象、18主动轴、19体SI、10.398672986kg条件质量；真实双铰链、轴向保持和手拧关闭件已进入24件CAD/采购增量，有限配合、同源静力及19项针对性测试通过。四色实际图已更新，门缝/最终审美、完整制造与电气仍待资格。003运行模型保持原身份；新结构未冒充旧训练版本。

当前电气：[精确驱动资料与18轴端点](../hardware/power_release_checkpoint.md)绑定478件源、17CAN＋独立5V TTL。[绝对阈值制动候选](../hardware/absolute_brake_chopper_checkpoint.md)已补实际可编辑KiCad、原生针脚/网络核对、阈值角点和真实NGSPICE行为/故障对照；名义及单电阻断开峰值约26.08V，关闭制动反例被检出。这仍未覆盖PCB时序/热、完整断开、冷启动或安装资格；供电保护、制造线束和实机启用门槛保留，未改CAD/SI或003包。

后续[制动安装比较](../hardware/brake_packaging_checkpoint.md)提供独立48件CAD增量、525件装配源和10.486951740kg条件SI；零位原生配合、21个有限转向／低姿态及同版静力已通过。PCB仍是预留，热／工具／线束和连续扫掠未放行；没有替换上面的478件基线或11凸体003运行模型。

当前供电增量：[独立原生制动板](../hardware/brake_pcb_checkpoint.md)提供44个板上元件、8个外置电阻、同版原理图／PCB、35条信号连接和45件包络STEP。KiCad DRC与复制项目检查均为0违规／0未连接，实际破坏焊盘或反馈走线均被拒绝；42项相关测试通过。PCB包络落在前轮预留内，但质量、真实固定、功率／散热、冷启动及急停使能链仍待闭合；未改写上述硬件参数或11凸体交付。

历史初始训练版本：[460件 Sai_Lab 初始训练检查点](training_checkpoint_handoff.md)。同源一体头壳、18主动轴、10.430762603kg；MJCF/URDF、完整SI参数、软脚底、四色实际图和运行入口已打包。实际65/18接口与0.2秒自由根站立冒烟通过，零初始自碰撞候选、零求解器警告；解压校验见[打包检查](../evidence/training_checkpoint_bundle_check.json)。完整制造、电气、步行/转向/夹拖及第三、第四阶段仍未完成；不是硬件冻结，不把旧动作当本版通过。

[单件头壳结构说明](one_piece_head_checkpoint.md)记录10姿态、33核心平移及126同源静力筛查，完整装配仍未通过。

# Goose_V0.1 — 工程与原始资料入口

历史整机结构增量：[固定机壳到内部框架的四处连接](torso_shell_mount_checkpoint.md)。独立462个显示对象、18轴、10.4408944kg条件质量，比446件版增加36.198g；30件名义原生CAD/五金、19体SI参数与采购表已保存，18个有限姿态及两组63个静力工况通过。外部轮廓和连续头壳保持；翼门/接缝、整机强度、电气与同版动力学仍待闭合，三、四阶段未完成。

最新局部修正：[头壳后缘与相机闭合检查点](camera_head_closure_checkpoint.md)。原生 CAD 已去除头壳后缘台阶，并补上相机面与头壳之间的连续空心鼻罩；独立候选为446个显示对象、18轴、10.4046964kg条件质量，比419件版增加2.29248g。十个有限头部姿态与同源静力筛查通过；完整装配、制造、审美和训练放行仍未通过。新版[头部近景](../images/microduck_color_blocking_446_parts/cream_head_detail.png)及[四色实际渲染](microduck_color_blocking_446_parts.md)与原生装配同源。

整机增量汇总：[419件装配与静力参数候选](integrated_hardware_candidate.md)。前端夹持、相机架、电源和计算板固定件汇入同一份源与19体闭合姿态惯量，条件质量10.4024039kg，比默认版增加44.548g；嘴尖20N／中部50N各63个静力工况通过，嘴尖50N的63个超载失败保留。右膝静力余量约0.09Nm，最终装配质量与动态余量仍需收敛。此候选尚无同版新碰撞/动力学模型，不是新训练或制造放行，默认344件版保持不变。

**现行默认模型入口：[整机机械与物理检查点](mechanical_integration_checkpoint.md)。** 当前344件、18主动轴、10.3578562kg条件质量；真实可更换夹持组件和四组上喙固定紧固已合入源几何、完整惯量、MJCF/URDF与碰撞模型。63个静力工况、限定短时站立和实际两垫对预置50g物体的保持/受拉通过。真实垫面使旧低位参考从24mm变为43.5mm；15mm目标的36组有限姿态筛查没有可用组合，尚未地面拾取。**第三、第四阶段、训练硬冻结与最终制造外观仍未完成。** 完整装配/承力、供电保护、实际硬件控制和整机任务仍待闭合。

独立主线试验：[前端夹取与连续动作检查点](tip_grip_checkpoint.md)。六件替换候选仅增重1.673g，保留18轴；补入双脚承重前馈并修正路径后，19.9秒完成自由根站立→地面50g样件夹取→抬升保持→放回→回站，保持段最低间隙约73.7mm、最大机身倾角约2.12°。无超过0.2mm的非脚部碰撞候选、速度越限或求解器警告，但颈根6次控制请求被连续力矩上限截断，严格完整门槛仍为false。候选源和参数独立保存，未覆盖默认装配，未训练硬冻结；早期碰地及掉落失败保留。

电气软件增量：[当前18轴硬件通信检查点](../hardware/current_hybrid_control_checkpoint.md)。选定USB-CAN-A串口协议、AK V3与17CAN+独立TTL调度、有限被动采集和故障处理已实现；65项软件/PTY检查通过。当前电机／固件档案、供电保护、独立急停和实物通信仍未验证，不能直接通电或宣布整机完成。

整机安装增量：[两块电源板的框架固定](power_module_mount_checkpoint.md)。按厂商真实安装孔补齐两件载板和完整紧固叠层，36件原生CAD、STEP/STL及84,192个闭合quad源已保存；与现行框架、机壳和活动髋部的34个有限姿态筛查通过。保留现有电源/散热/线束质量预留后保守新增10.122g，机身与关节包络未改变。增量采购表和装配图已交付；接线、散热、机壳支承及同版整机集成仍待完成，未覆盖默认344件装配。

整机安装增量：[计算板与集线器的框架固定](compute_module_mount_checkpoint.md)。按两套真实孔位生成42件原生固定/替换件和完整紧固叠层，净增28.991g；有效源的34个有限姿态筛查通过，Radxa无效厂商主实体对应13组接触未确认。完整安装仍未通过；USB-CAN-A官方78.52×18.36mm尺寸也揭示旧预留不足。保留失败源，不宣称制造或整机完成。

配色重新验收：[446件 MicroDuck 色块分区候选](microduck_color_blocking_446_parts.md)，四张同版实际渲染：[Cream](../images/microduck_color_blocking_446_parts/cream.png)、[Graphite](../images/microduck_color_blocking_446_parts/graphite.png)、[Lavender](../images/microduck_color_blocking_446_parts/lavender.png)、[Sky](../images/microduck_color_blocking_446_parts/sky.png)。主壳、中性检修门/脸板、深色骨架和嘴脚点缀分别配色；头部闭合与后缘修正已进入这一版源，仍等待用户审美验收。存在前部过渡空隙的[419件图](microduck_color_blocking_419_parts.md)、[344件图](microduck_color_blocking_344_parts.md)、[314件图](microduck_color_blocking_314_parts.md)与[292件图](microduck_color_blocking.md)保留为历史，不能混称本版。

整机装配增量：[真实相机承力架与视野检查点](camera_installation_checkpoint.md)。完整原厂三层PCB包络筛查及三个自研原生件已保存；相对现有头架和展示光学件净增约3.762g，保留夹嘴轴承固定结构。现有夹取动作中样件被上嘴遮挡，需要先观察定位；一组低头观察姿态通过有限几何/名义静力检查。相机候选尚未并入默认装配，插头、固定五金、线束、标定及同版整机回归仍未闭合，没有追加PPO。

[36件真实夹持/框架安装](../evidence/mechanical_grip_installation.json)核对六个旧对应件替换、净增15.51g及80g预留不抵扣；[组件说明](grip_cassette_candidate.md)列出名义几何及未放行的材料、强度、工具路径。现有成功不代表可直接打印装机或下单。

## 历史检查点与原始资料

[314件安装前检查点](mechanical_checkpoint_pre_grip_installation.md)及[安装前参数预估](../evidence/grip_cassette_parameter_delta_pre_install.json)保留当时的未合入状态；完整原运行资产可由基线记录的Git提交恢复。旧参考、质量和任务结果不得沿用当前验证结论。

以下数字和模型保留其当时版本，不能作为最新参数。

本轮新增：[当前装配的同版参数与运动学参考](body_bay_reference_handoff.md)。19个刚体、18轴及10.0525kg条件质量已导出同版MJCF/URDF和CSV，保留262件实际装配显示件；仅用于坐标、惯量和装配核对，碰撞模型未完成，不能用于行走/夹拖训练。第三、第四阶段及最终外观仍未通过。

最新检查点：[机箱容纳与高髋原生装配](body_bay_native_checkpoint.md)。134件新建/重建原生实件已与新轴位、条件质量10.0525kg及逐体惯量合并；63组静力和13组限定任务姿态的下半身碰撞筛查通过，262件实际Blender源全部quad拓扑通过。**第三、第四阶段、新训练版本及最终外观仍未冻结**；完整载荷链、供电回馈、连续运动和一项原生体内分类分歧尚未关闭。颈腿护罩研究完成，优先白色薄分段开放罩，尚未加入实际装配。

最新工作：[训练前整机髋部布局比较](hip_architecture_optimization.md)与[颈腿护罩研究](neck_leg_cover_trade_study.md)。用户尚未开始Sai_Lab训练，现按整机可落地与外观共同优化，旧参数不限制新布局。五组髋部候选完成静力和有限包络比较，**没有整体容纳放行候选**；不把大开口试验或未通过面积阈值的Blender皮壳当成最终外观。优先试白色分段、内侧开放的连杆护罩，局部TPU遮线作为比较；尚未制作护罩CAD。

新增[髋侧倾至俯仰连接件及两组开口诊断](hip_carrier_candidate.md)保留原生CAD、29组限定碰撞检查和9.643kg条件台账；静力及局部无交集不等于全机可制造。下一轮训练交付仍待整体布置、承力框架、真实模块容纳与新同版质量/惯量闭合。

最新制造候选：[追加两小时检查点](stage_three_four_extension.md)。六组带孔叉架、独立后支承、弹性脚底、转向筛查及同版质量台账已保存。保守条件质量9.608kg，63组静力通过，自由脚夹具23/24通过。**第三、第四阶段及最终外观仍未通过**，不能直接采购装机或作为新冻结训练版本。[实际候选图](../images/pitch_foot_candidate/three_quarter.png)保留未制造部分状态。

新增最终交付要求：[实体与电子版外观一致](manufacturing_appearance_acceptance.md)。最终图片必须直接来自同版制造装配；现有第二阶段图片不是最终制造外观。[原生曲面壳体增量](../cad/exports/manufacturing_skins/manifest.json)仅包含八件外壳基础实体，[一致性检查](../evidence/manufacturing_appearance_gate.json)通过不等同整机或最终外观放行。

[第三、第四阶段中途检查点](stage_three_manufacturing_checkpoint.md)：八件原生壳体与六件带孔电机接口已验证；头部安装口与统一光学位姿修正通过限定包络检查，实际全机连接与供电尚未放行。[安装候选预览](../images/manufacturing_skin_candidate/three_quarter.png)及其 [Blender 源](../cad/source/manufacturing_preview/quad_assembly.blend)仍包含第二阶段未制造结构，不能当作最终外观。[壳体物理参数增量](../evidence/manufacturing_skin_parameter_delta.json)为名义 8.825kg，仅替换壳体与相机位置；未发布新冻结模型。

第二阶段交接：[嘴部传动、低位接近与供电架构](stage_two_parameter_handoff.md)。**当前候选为 `goose_stage_two_si_v2`，18 轴、8.854 kg；嘴部和中颈驱动升级，名义及 4 个扰动低位往返通过。** 供电窗口/回馈保护与封闭头壳热能力仍阻止硬件硬冻结。Sai_Lab 新实验请显式选择第二阶段；下方第一阶段保持历史记录。

第一阶段交接：[18 轴结构与物理参数包](stage_one_parameter_handoff.md)。**约 8.62 kg、MJCF + URDF + 逐体惯量 + 统一 SI 契约 + PPO 入口已提供，可启动初训；硬件硬冻结尚未通过。** 嘴持续输出、电源配套和低位拾取控制的未决项与修改边界均在交接页列明。旧 16 轴 RC2 资料不能作为本版训练输入。

执行节奏：[整机里程碑与 Sai_Lab 交接门槛](hardware_milestones.md)。当前先收敛大结构，再交付训练基线，制造细节随后完善。

硬件主线：[已确认外观到完整硬件交付](accepted_hardware_execution.md)，包含交付证明要求和同版质量／颈部负载初筛。

最新硬件增量：[脚底分层候选与嘴部传动筛查](foot_support_and_beak_transmission.md)；保留接地轮廓、增加金属板毛坯，条件减重约 280 g，固定接口尚未完成。

当前已确认外观入口：[饱满机身／大眼／流线鹅掌候选](fuller_exterior_review.md)。按最新三条反馈扩大机身并检查八组模块预留，恢复大眼表达、调整脚掌；**用户已确认这一阶段外观并授权上传 GitHub**；进入同版硬件落地，物理和制造仍未通过。

[上一版铰接嘴候选](hinged_beak_exterior_review.md)保留对照；约 50 N 仍为待验证目标。

[肩胸与收尾曲面候选](sculpted_exterior_review.md)因头嘴不协调、身体不够简约而被后续方向取代，不是获批外观。

[流线型候选失败记录](streamlined_exterior_review.md)：用户否决头身卵形比例，当前继续重做形体，不能进入物理放行。

本目录保留了交接包中的图片、文档、工作簿和 CSV；包内旧方案仍可完整查阅。**当前工程候选**按用户后来确认的目标推进：室内平地双足鹅、游戏般的好奇和捣蛋感、叼起与拖拽同等重要、简约手动翼形检修门、鹅叫和头颈动作。所有设计须同时满足外观方向与可制造、可运行。概念图不是尺寸或性能依据。

**当前状态：fuller 外观已获用户确认；旧 RC2 外观曾被否决，其物理结果不适用于新版。制造和采购均未放行。** 原交接包的 [B 步行鹅](concepts/history/walker_b_selected_reference.png) 及用户再次指定的 [R2 闭嘴尖嘴](concepts/r2_pointed_beak_closed_reference.jpg)、[R2 平行张嘴](concepts/r2_pointed_beak_parallel_open_reference.jpg) 是历史外观基线；用户随后允许按反馈与审美重新设计，最新铰接嘴候选优先。旧 RC2 虽已有可编辑 CAD 源、STEP/STL、MuJoCo 模型、统一 SI 控制/训练接口和 Godot/Jolt 接收器，但[实际外形](exterior_review.md)严重偏离原图；旧几何和对应的静态试验不能作为新版放行证据。初版缩壳试验曾让嘴代替双脚撑地；[短鞋与前移膝轴候选](forward_knee_trade_study.md)找到无物体的双脚低位保持。[小机箱与前颈够地候选](r2_compact_front_reach_review.md)把视觉机箱收至 `280×190×180 mm`；随后[同版尖嘴修正](r2_pointed_bill_mechanism_gate.md)消除了原视觉上下喙壳的实体穿插，并按 R2 四连杆的前移轨迹张嘴。修正后的简化模型通过指定坐姿 50 g 等效力保持；它仍未复刻原图、夹住物体、单脚行走或完成可装配结构。[MicroDuck Max Pro 对照](microduck_max_pro_baseline.md)明确了可沿用的双足方法和 Goose 必须新增的腿脚机动、真实夹取与拖拽能力；18 主动轴已有独立第二阶段训练候选，第一阶段亦保留，旧 RC2 规格仍是 16 轴历史模型。UnitySim2Sim、BevySim2Sim 仍应从引擎无关的 SI 契约适配，尚未实现或验证。

| 历史 RC2 与过渡资料入口（18 轴请使用上方交接包） | 内容 |
|---|---|
| [RC2 历史规格](../configs/robot_spec.json) | 机体、16 主动轴候选、尺寸、器件、动作边界与单位 |
| [交付完整性核查](../evidence/delivery_integrity_rc2.json) | 59 个交接文件、本地链接、363 个 CAD 文件哈希及现行 BOM 数量核对；仅证明资料完整 |
| [CAD 清单](../cad/exports/cad_manifest.json) / [整机 STEP](../cad/exports/goose_rc2_assembly.step) | 打印件、材料/质量、各 STEP/STL；清单标示制造验收状态 |
| [RC2 候选 BOM](../hardware/goose_rc2_bom.xlsx) / [CSV](../hardware/goose_rc2_bom.csv) / [接线装配稿](../hardware/goose_rc2_wiring_and_assembly.md) | 与 CAD/规格同步的工作清单；中国报价、线束、螺钉和额定核查未放行 |
| [MuJoCo 模型](../models/full/robot.xml) / [跨引擎中立数据](../models/full/rigid_transfer.json) | 自由根、双腿、头颈、嘴部闭环与质量惯量，运行接口为 SI |
| [工程基线](engineering_baseline.md) / [整机放行判定](release_readiness.md) / [早期验收快照](../evidence/design_review_baseline.json) | 当前门槛、已通过证据及不能下单/交付的缺口；早期记录只保留溯源 |
| [本轮抽样装配](../evidence/part_clearance_sampled_rc2.json) / [叼取](../evidence/grasp_50g_rc2.json) / [短距牵引](../evidence/drag_short_pull_rc2.json) / [Jolt v5 站立](../evidence/godot_jolt_standing_v5_rc2.json) | 同一模型哈希下的分项证据，范围见各文件；[旧叼取姿态站立失败](../evidence/godot_jolt_ground_grasp_stance_failure_rc2.json)保留 |
| [游戏动作观察](gameplay_sources_review.md) / [行为要求](behavior_requirements.md) | 叼、拖、停顿、回望、鹅叫；外部视频未实际取得画面时明确标注 |
| [实际外形核查](exterior_review.md) | 当前 CAD 渲染与游戏鹅的差距、下一版外饰和工程复查门槛 |
| [后掌候选与物理复核](stance_layout_review.md) | 脚型对照、条件质量与重心、MuJoCo 限力试验；外观及动力学均未放行 |
| [MicroDuck Max Pro 对照](microduck_max_pro_baseline.md) | 原机质量/脚型/关节/训练方法量测；Goose 6 轴腿与 18 主动轴新候选的验证条件 |
| [R2 加长尖嘴外观对照](../images/r2_pointed_max_pro_three_quarter_candidate.png) / [张嘴细节](../images/r2_pointed_max_pro_open_detail_candidate.png) | 仅供 B/R2 视觉比较，未通过外观或工程放行 |
| [R2 高颈比例侧视](../images/r2_proportion_side_candidate.png) / [斜视](../images/r2_proportion_three_quarter_candidate.png) / [平行张嘴](../images/r2_proportion_open_beak_candidate.png) | 前一轮视觉候选；仍有头、颈、脚的大轮廓偏差，未通过外观验收 |
| [六轴腿与单脚证据](../evidence/physics_stance_trial_r2_proportion_ankle_roll_single_support.json) / [踝部包装筛查](../evidence/ankle_roll_package_screen_r2_proportion.json) | 双脚侧移有改善，三组单脚卸载均失败；第六轴未放行 |
| [较紧凑 R2 比例侧视](../images/r2_ankle_clearance_side_candidate.png) / [斜视](../images/r2_ankle_clearance_three_quarter_candidate.png) / [平行张嘴](../images/r2_ankle_clearance_open_beak_candidate.png) | 上一轮外观候选；踝轴保留高度，仍未通过外观和制造验收 |
| [新比例低头与单脚试验](../evidence/physics_stance_trial_r2_ankle_clearance_six_axis.json) / [踝电机本体盒](../evidence/ankle_roll_package_screen_r2_ankle_clearance.json) | 站立 2 秒，低头与单脚失败；鞋壳、电机承力与线束仍未闭合 |
| [缩壳站立侧视](../images/r2_compact_body_side_candidate.png) / [斜视](../images/r2_compact_body_three_quarter_candidate.png) / [坐姿低头](../images/r2_compact_body_seated_reach_side_candidate.png) | 最新视觉对照；缩壳和双腿折低只改善几何可达性，外观复刻仍未通过 |
| [缩壳视觉 STEP 与清单](../cad/exports/goose_r2_compact_body_visual_candidate_manifest.json) / [坐姿几何](../evidence/exterior_seated_reach_r2_compact_body_tip40.json) / [坐姿接触试验](../evidence/physics_seated_reach_r2_compact_body_tip40.json) | 视觉实体不可直接制造；嘴端受地面反力，未验证坐姿夹物 |
| [短鞋／前移膝轴对照](forward_knee_trade_study.md) / [候选斜视](../images/r2_forward_knee_three_quarter_candidate.png) / [坐姿侧视](../images/r2_forward_knee_seated_reach_x280_side_candidate.png) | 保留缩壳与 R2 尖嘴；双脚承重的无物体坐姿通过 2 秒简化试验，50 g 仅过静力初筛；外观、真实夹取和步行未放行 |
| [紧凑轮廓审查](r2_compact_silhouette_review.md) / [闭嘴斜视](../images/r2_compact_silhouette_v51_three_quarter_candidate.png) / [张嘴近景](../images/r2_compact_silhouette_v51_open_beak_candidate.png) | 机箱 `310×190×180 mm` 视觉草模；一条坐姿几何路径和 50 g 等效力低位保持通过初筛，仍无夹持、步行或制造放行 |
| [小机箱与前颈够地审查](r2_compact_front_reach_review.md) / [站姿斜视](../images/r2_compact_front_reach_v53_three_quarter_candidate.png) / [坐姿侧视](../images/r2_compact_front_reach_v53_seated_side_candidate.png) | 视觉机箱前后缩至 `280 mm`；15 点坐姿工作区几何初筛通过 13 点，嘴尖高 15／25 mm 的 50 g 外力代理保持通过，10 mm 动态碰地失败；外观和制造仍未放行 |
| [尖嘴实体与 R2 机构一致性](r2_pointed_bill_mechanism_gate.md) / [闭嘴近景](../images/r2_nonintersecting_bill_v55_closed_detail_candidate.png) / [平行张嘴近景](../images/r2_nonintersecting_bill_v55_open_detail_candidate.png) | 消除原视觉喙壳约 `9.13 cm³` 穿插，九点理想运动中两片橙色壳零穿插；同版低位外力保持仅为无物体必要初筛。旧 RC2 嘴机构型号、轴距和传动比均不符合指定 R2，不能直接换皮 |
| [小机身／高髋／前颈坐姿拾取权衡](seated_pickup_layout_trade.md) / [几何记录](../evidence/seated_pickup_layout_trade_v55.json) | 再缩机箱没有增加已筛可达点；髋上移 25 mm 与现翼门外形冲突，更宽双脚增加单脚换重心距离；15 mm 嘴尖目标在张嘴后可能撞地，均未制造或夹取放行 |
| [内藏嘴部电机必要包络](r2_pointed_bill_mechanism_gate.md#内藏电机与传动带的必要包络初筛) / [几何记录](../evidence/r2_internal_belt_gross_package_v61.json) | XL330 和假定 2:1 带路可在头壳／嘴根粗包络中放下；侧颊、细长立耳仍不符合指定外观，未放行制造和采购 |
| [头壳包覆 v69](r2_pointed_bill_mechanism_gate.md) / [闭嘴斜视](../images/r2_head_wrap_v69_closed_three_quarter_candidate.png) / [张嘴近景](../images/r2_head_wrap_v69_open_detail_candidate.png) / [实体核查](../evidence/r2_head_wrap_gross_package_v69.json) | 收回外突大侧颊；九点理想张合的头壳／尖嘴／立耳无实体互穿。仍未复刻指定外观，也不是可装配、可采购或已验证夹拖的结构 |
| [头嘴与低鞋门 v72](r2_pointed_bill_mechanism_gate.md) / [闭嘴斜视](../images/r2_head_wrap_v72_closed_three_quarter_candidate.png) / [平行张嘴](../images/r2_head_wrap_v72_open_detail_candidate.png) / [实体核查](../evidence/r2_head_wrap_gross_package_v72.json) | 修正相机面板与固定上喙干涉并保留隐藏电机／带路的假设包络；头罩更圆、翼门和鞋底更薄。仍未通过外观、装配、夹拖或采购验收 |
| [薄下喙 v73](r2_pointed_bill_mechanism_gate.md) / [闭嘴斜视](../images/r2_slim_bill_v73_closed_three_quarter_candidate.png) / [张嘴近景](../images/r2_slim_bill_v73_open_detail_candidate.png) / [坐姿侧视](../images/r2_slim_bill_v73_sit90_x300_z25_head60_open_side_candidate.png) | 保留尖嘴、平行张嘴与头内藏驱动方向；一处下蹲视觉姿态通过有限几何净空筛查。仍未复刻外观，也未证实真实抓拖、步行或可打印装配 |
| [上颈默认折姿 v79](exterior_review.md) / [侧视](../images/r2_neck_rest15_v79_closed_side_candidate.png) / [斜视](../images/r2_neck_rest15_v79_closed_three_quarter_candidate.png) | 上颈向后折 15°，头嘴保持水平；同一低位九目标仍过 8/9，但拾取终点多需 15° 头颈关节转角。仅作外观对照，不替换 v73，也未通过外观或工程验收 |
| [贴合曲面的翼形门 v81](exterior_review.md) / [侧视](../images/r2_conformal_wing_v81_closed_side_candidate.png) / [斜视](../images/r2_conformal_wing_v81_closed_three_quarter_candidate.png) | 原机身轮廓上切分贴面门片，保留简约翼门方向；低位九目标仍过 8/9。门片缺薄壳、铰链和锁止，仅为局部外观备选，不能打印装配；整机仍按未通过外观的 v73 工作候选继续 |
| [低头罩与长颈比例 v92](r2_whole_proportions_review.md) / [闭嘴斜视](../images/r2_whole_proportions_v92_closed_three_quarter_candidate.png) / [张嘴近景](../images/r2_whole_proportions_v92_open_detail_candidate.png) / [坐姿侧视](../images/r2_whole_proportions_v92_sit90_open_side_candidate.png) | 同版低位九目标几何初筛 9/9、嘴部粗包络通过；条件重心升高约 5.62 mm，所需头颈角度、真实夹拖与整机外观均未验收。只作为比例比较，不能打印装配或采购 |
| [连续头罩与内收四杆 v95](r2_whole_proportions_review.md#v95-嘴根与连续头罩的局部试样) / [闭嘴整机](../images/r2_swept_head_v95_closed_three_quarter_candidate.png) / [张嘴整机](../images/r2_swept_head_v95_open_three_quarter_candidate.png) | 去掉 v92 的矩形头罩缺口；开闭两端所列头罩／连杆实体不互穿，但中途只做有限采样；原头罩网格的退化面已另存清理版，仍非可装配打印件。外观与同版物理未通过 |
| [居中脚掌 v96](r2_whole_proportions_review.md#v96-脚掌居中站姿与低位任务一起看) / [站姿侧视](../images/r2_centered_foot_v96_closed_side_candidate.png) / [坐姿张嘴](../images/r2_centered_foot_v96_sit90_open_side_candidate.png) | 只把两鞋后移 `20 mm`；条件站姿余量改善，低位叼取前方余量变小，髋部负载仍未过粗筛。保留比较，不定版或下单 |
| [v95 整机对齐闸门](../evidence/r2_swept_head_v95_system_alignment.json) / [放行总览](release_readiness.md) | 最新视觉 R2 与 RC2 模型在嘴机构轴距、电机、传动比和机身包络上不一致；旧模型试验不得用于新版放行 |
| [v73 与运行模型一致性闸门](../evidence/r2_slim_bill_v73_model_alignment.json) | 明确检出当前 RC2 的 `18 mm/XC330/1:1/16 轴` 与 v73 视觉 R2 的 `14 mm/XL330/暂定 2:1` 不一致；旧模型与 CAD 不能作为 v73 的 Sai_Lab、采购或制造交付 |
| [结构/执行器核查](servo_mount_geometry_review.md) / [电源事实](power_bus_facts.md) | 原厂几何、电气限制与来源 |
| [跨引擎验收清单](backend_conformance_facts.md) | Godot 局部单位转换；Unity/Bevy 后续应逐项证实的适配条件 |
| [双足控制审查](locomotion_review.md) | 旧训练失败根因、现行站姿控制和独立步态判据；行走仍未通过 |
| [打印机与材料](printer_selection.md) / [采购包装核查](procurement_packaging_facts.md) | 当前建议 X2D 普通打印配置、P2S 为 PETG 经济选项；中国现价与供货待核 |
| [鹅叫素材](../models/full/audio/honk.wav) / [音频清单](../models/full/audio/audio_manifest.json) | 自制声音，用于动作表达；扬声器音量须实物验收 |

## 保留的交接包与设计历程

- [conversation_handoff.md](conversation_handoff.md) 和[交接时的机器人 README](../source/robot_readme_handoff.md)记录原交接时的目标和决策顺序；其 18 轴/XL330 与“尚无 CAD”等表述是**当时状态**，不能覆盖此后的 16 轴/XC330 工程候选。
- [嘴部 R2 原说明](beak_r2.md)、[机构图复核](kinematic_review.md)、[整体旧结构](walker_structure.md) 与 [原采购工作簿](../hardware/walker_r2_bom.xlsx) 都保留原始设计线索；旧工作簿不是当前订货单。
- [原嘴部采购 CSV](../hardware/beak_r2_purchase.csv)、[原打印件 CSV](../hardware/beak_r2_print_parts.csv)、[图片资料库](concepts/index.html) 和 [完整导入索引](../source/asset_index.md) 可查旧版与用户补图。包内图片、文档、表格保留；仅原包 README 修复两处本地相对链接。
- 当前外形参考 [用户的翼形检修门批注图](concepts/wing_access_reference.png)；门手动开合、抽象曲面，不画写实羽毛、不增加翅膀电机。

构建入口位于仓库的 `scripts/cad/build_goose_cad.py`、`scripts/models/build_goose.py`、`scripts/models/export_goose_transfer.py`、`scripts/training/train_goose_rsl.py`。模型和加工验收结果必须记录所用规格与文件哈希，不能把早期失败试验的输出覆盖成成功。

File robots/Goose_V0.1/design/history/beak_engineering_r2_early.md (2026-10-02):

# Goose_V0.1 — 嘴部机械方案 R2
## 一体式鹅喙平行夹持机构

日期：2026-09-27  
状态：方案设计与理想平面运动学算例；不是制造 CAD 或实机验收。  
范围：替换步行鹅的嘴部机构及对应物料；已选定的身体、双足和颈部总体方向保持不变。

## 1. 设计结论

采用“固定上喙 + 平行运动下喙 + 单舵机 + 嘴内柔顺接触垫”。
上下喙本身就是两片夹指，不在下巴外挂另一把夹爪。

外部轮廓和内部接触面分开设计：外部收尖、喙根较高、上背拱起，闭合时形成鹅嘴；内部设置相对的夹持面。灵活性由下喙运动轨迹、接触形状及现有头部滚转共同提供，不靠新增多台嘴部电机。

首轮目标是拾取指定轻物并可控释放。50 g 为第一阶段试验负载；100 g 为升级测试工况，不是适用于所有形状的额定载荷。鹅嘴台架通过不等于整机持物步行通过。

## 2. 造型规则

- 俯视从宽根渐收至窄、钝的前端，不做矩形前沿和全长等宽的鸭嘴板。
- 侧视上喙有高度和略拱的上背，下喙较浅，闭合后形成连续楔形；不使用猛禽式大钩尖。
- 上喙的高度来自空腔与加强筋，而非实心加厚。
- 深色部分只出现在口缝和口腔接触区；工作垫和机构不形成外伸的第三个夹爪。
- 相机仍装在固定头架上，不装在运动下喙上。上喙抬高后必须检查相机视锥，不能假定原视野不变。
- 两颊传动罩随真实零件包络设计；不得为了隐藏机构而随意放大整个鹅头。

以下是原型设计输入，不是由已有图片测得的尺寸：

| 参数 | 原型目标 |
| --- | --- |
| 外露喙长 | 约 60–65 mm |
| 橙色喙根宽 | 约 30–34 mm |
| 前端宽 | 约 12–14 mm，圆钝收尖 |
| 外露上/下喙闭合根部总高 | 约 26–30 mm；后方两颊机构空间单独检查 |
| 常用净开口 | 约 0–25 mm |
| 最大净开口目标 | 约 30 mm；理想运动行程约 32.1 mm |
| 可换接触垫厚 | 初试约 2 mm，按压缩量和保留结构调整 |
| 嘴部模块质量目标 | 不超过 65 g，包含嘴部电机、传动、支架、软垫与线材；不含相机、头壳和颈关节 |

嘴部重量必须独立称量，再与相机、头壳和头部关节合并形成颈部真实末端负载，不能把 65 g 当作整个头重。

## 3. 机构拓扑

### 3.1 固定部分

上喙固定在口部承力架上。承力架连接头部内框，并承接下喙的两个固定转轴。电机位于喙根后方，不放在嘴尖。

### 3.2 运动部分

采用竖向固定支点的平行四边形机构：

- 两个固定转轴在侧视中上下排列。
- 两根等长摆杆连接下喙后部的两个等间距转轴。
- 下喙与其后部立耳构成同一刚性连杆，因此理想运动时下喙姿态不变。
- 左右两侧各有两根摆杆，共四根；横向同轴支撑抑制偏心抓取造成的歪斜。
- 一台舵机经约 2:1 减速驱动一根固定转轴，四连杆约束其余运动。
- 两侧支撑的同轴度和轴向释放必须明确，避免打印公差使双侧机构卡滞。

这是让下喙本身运动的夹持机构，不是把成品平行夹爪塞进另一个鹅嘴外壳。

### 3.3 与普通张嘴铰链的差异

普通转动下喙的内表面会随开口倾斜，物体可能只受到边缘接触；斜接触还可能产生向外的分力。平行下喙的设计目的，是让有效接触面在不同开口下保持相对，减少对接触角度的依赖。软垫摩擦、物体形状和偏心力矩仍然需要验证。

代价是根部零件数量增加，而且下喙不是纯竖直移动。这些代价在本方案中显式保留，不称为“完美平行直线夹爪”。

### 3.4 已计算的理想平面运动学

局部坐标：X 向前，Z 向上，转轴沿 Y。以下数字只是可行的初始参数组。

- 两根等长摆杆：L = 25 mm。
- 固定支点竖向间距：h = 14 mm；运动支点间距相同。
- 摆杆角度 q 相对 +X 测量。
- 闭合位置 q = +40°；张开位置 q = −40°。
- 舵机/摆杆角位移比 i = 2。

令 A=(0,0)、D=(0,h)，则：
B=(L cos q, L sin q)
C=B+(0,h)

理想下喙参考平面的开口变化：
g(q) = L [sin(40°) − sin(q)]

相对闭合位置的水平位移：
dx(q) = L [cos(q) − cos(40°)]

算例结果：

| 项目 | 结果 |
| --- | --- |
| 下喙理想开口行程 | 32.139 mm |
| 行程内最大前向偏移 | 5.849 mm |
| 全开与闭合的水平位置差 | 0 mm |
| 理想下喙姿态变化 | 0° |
| 2:1 减速下的舵机角行程 | 160° |
| 距离支点/摆杆共线的最近角度裕量 | 50° |

全行程没有经过这组理想连杆的共线位形，但这不等于三维零件不干涉。尚未验证齿轮、轴承法兰、连接螺钉、相机、护罩和上下喙之间的碰撞。

特别注意：闭合过程存在水平扫动，不能宣称夹点完全固定。需要降低接触阶段速度；对被固定物体，必要时用头部运动补偿。夹取自由物体时，要观察其是否被下喙推走。

2:1 只是传动比设计输入。齿数、模数、轴向错层和轴承安装必须由完整装配决定；14 mm 支点间距也允许为真实齿轮包络调整。不能直接把这组参数当作一张已解决全部装配的加工图。

## 4. 接触面，而非额外手指

### 4.1 同一副嘴的三个接触区

| 区域 | 几何和材料意图 | 首轮测试对象 |
| --- | --- | --- |
| 嘴尖前约 10–15 mm | 窄、相对的柔性接触面，前沿钝化 | 拉环、线绳、布条边缘、有可接近边缘的薄片 |
| 中段 | 浅 V 形软槽，初版按长条物沿嘴长方向定位 | 笔杆、短棒、轻型工具柄 |
| 靠近嘴根的内侧 | 较宽软垫和浅容纳凹区，不做闭合锁钩 | 指定小积木、轻型壳体、局部较厚的把手 |

这是同一副可换衬垫上的分区，不是三套末端工具，也不需要自动换嘴机构。

### 4.2 被动微顺应

下喙内放一个可拆压垫托，以小转轴和弹性回正件允许约 ±4° 的俯仰微调；设置硬限位，不允许整个嘴尖软塌。上喙使用固定柔性垫。

该被动角度不是新增主动自由度，不增加电机。目标是让偏斜的小物体获得更好的接触，而不是实现完整包络、灵巧手或已验证的“自适应抓取”。

Yale OpenHand 证明了被动柔顺和定制接触面是一条可研究的抓取路线；其手型、尺度和载荷不构成本方案性能证据，也不直接复制其非商业 CAD。[R4]

### 4.3 侧头抓取

利用已有 head_roll 候选轴改变夹持方向。侧头约 60–90° 可以把上下夹变成侧向夹的姿态意图，但头颈真实可达范围、自碰撞及线缆扭转必须验证；本轮不假定已经有 90° 可用行程。

侧头不能让下喙穿过桌面。贴地硬币、没有可接近边缘的薄纸、扁平贴合件，均不作为第一版必达对象。优先夹物体的边、把手或拉环，而不是要求嘴跨越整个大瓶身。

## 5. 驱动选型与载荷算例

### 5.1 首选样件

使用一台 ROBOTIS DYNAMIXEL XL330-M288-T：

- 官方尺寸 20 × 34 × 26 mm，重量 18 g。
- 推荐 5 V，允许输入 3.7–6.0 V。
- 支持电流控制和基于电流的位置控制。
- 5 V 下的 0.52 N·m 是堵转扭矩，不能当持续工作能力。[R1]

本轮保留这台电机，不默认增加第二台嘴部电机或更换全部关节驱动。选择的重点是重量、可采购来源、可查询控制表，以及与既有候选总线的衔接。

官方美国商店本次可见列价 USD 27.49，但同页出现售罄标记和购物按钮，库存不能据此确定；中国交付和价格需要代理商确认，不作为现货下单承诺。[R2]

### 5.2 100 g 对置摩擦夹持算例

假设：

- 物体质量 m = 0.10 kg；
- 向上加速度 a = 3 m/s²；
- 接触摩擦系数 μ = 0.4（假设，不是所选硅胶实测值）；
- 安全系数 S = 2；
- 两侧均有接触，每侧法向力为 N；
- 不计物体偏心转矩，仅计算滑落。

所需单侧法向力：
N ≥ S m(g+a)/(2μ) ≈ 3.203 N

因此可先将指定物体测试的法向夹力放在每侧约 2–4 N 的研究范围，按实际滑移、压痕和材料情况调整。这个范围不是人体接触安全标准。

对理想平行机构，在切向接触力可忽略的简化下：
τ_motor ≈ N L cos(q)/(i η)

取 i=2、假设传动效率 η=0.65，得到约 0.047–0.062 N·m。尚未加入下喙重量、轴系摩擦的不确定性、齿隙、斜向反力和冲击。这个算例支持进入台架测试，不证明电机长期可靠。

若存在切向力，应用完整雅可比项，而不是继续使用仅竖直力公式。嘴长不直接出现在上述纯平移功率关系里，也不意味着嘴长不影响刚度、轴系反力和偏心转矩。

### 5.3 质量分配

| 部分 | 预算 |
| --- | --- |
| 口部电机 | 18 g（厂商规格） |
| 上下喙、根部架、摆杆、传动件、压垫托 | 约 20–24 g 设计预算 |
| 轴、衬套、紧固件 | 约 8–10 g 设计预算 |
| 软垫、弹性回正件 | 约 4–6 g 设计预算 |
| 线材、固定附件及余量 | 约 5–7 g 设计预算 |
| 合计 | 约 55–65 g 的目标范围，不是称重结果 |

100 g 物体和约 60 g 嘴部模块，即便不算相机/头壳，在某颈关节前方 0.20 m 也会贡献约 0.314 N·m 静态重力矩。嘴夹验证通过后仍需重新核算颈部；不能把嘴夹能力等同于整机搬运能力。

## 6. 嘴部候选采购表

以下只列嘴部增量；已有主控、相机、IMU、电池和躯干不重复采购。未锁定安装孔位和长度的物料，不伪造最终发料数量。

| 项目 | 初样用量 | 规格/来源 | 采购或制造状态 |
| --- | --- | --- | --- |
| 嘴部舵机 | 1 个 | XL330-M288-T [R1][R2] | 可查询产品；先确认库存。旧样件可复用 |
| 舵盘/电机接口件 | 1 套 | 与 X330 实际输出接口匹配 | 用官方尺寸核对，不猜孔距 |
| 主连杆轴 | 4 根候选 | 直径 3 mm 精密光轴/肩轴 | 长度、轴向保留方式待装配；不用螺纹段当滑动轴面 |
| 主转轴衬套 | 8 个候选 | igus JFM-0304-03：内径3、外径4.5、法兰外径7.5、长3 mm [R5] | 按固定/运动轴的双侧支撑初配；压配孔需试样 |
| 压垫微摆轴 | 1 根候选 | 直径约2 mm金属轴 | 长度与止挡待压垫托定型 |
| 上下接触垫 | 装机2件，初试2副 | 约2 mm厚，Shore A20–30 硅胶试样 | 原型可裁切；分区形状用打印模具浇注 |
| 弹性回正件 | 1 组 | 同批硅胶/弹性体小件 | 从样料制作并测回正与迟滞 |
| 软垫浇注材料 | 1 小包装或加工服务 | Dragon Skin 20 为可查的 A20 候选 [R6] | 不是必买进口品牌；替代品需硬度/硫化资料与实测 |
| 螺钉、垫片、保留件 | 1 组 | M2为主，按X330和装配孔制式匹配 | 精确长度/数量由CAD导出 |
| 口部线材与应力释放 | 1 套 | 匹配所选舵机的原厂/验证线材 | 优先复用，不新增无必要供电体系 |
| 台架通信与5 V限流供电 | 已有则复用 | U2D2或现有兼容接口+独立合适电源 | U2D2只通信，不给舵机供电 [R7] |
| 夹力/拉脱力测试工具 | 1 套，已有则复用 | 小量程测力计或校准测力工装 | 这是台架工具，不是默认新增机载传感器 |

不对未报价打印件、轴系加工和中国交付成本给出虚构总价。

### 打印与加工件

| 零件 | 初样数量 | 制造要求 |
| --- | --- | --- |
| 上喙与固定安装结构 | 1 | 空腔+筋；相机视野检查 |
| 下喙刚性本体/后部连接架 | 1 | 夹面、轴孔和接触垫安装基准 |
| 根部左右支架/两颊罩 | 1套 | 电机、轴系、护罩运动间隙 |
| 等长摆杆 | 4 | 中心距一致；孔的加工/校准方法明确 |
| 约2:1传动齿轮 | 2 | 模数/齿数/厚度待真实包络；避开相邻轴与法兰 |
| 下喙微顺应压垫托 | 1 | ±4°候选止挡与回正件座 |
| 硅胶垫模具 | 1套 | 上下垫；脱模与机械锁扣/穿孔 |
| 台架安装座 | 1 | 固定头架，观察嘴部运动，不掩饰整机能力 |

第一轮可用 PETG 做装配和低载台架，承力件及齿轮的正式材料/工艺按寿命试验决定，PA12可列为加工候选。硅胶优先采用机械限位/穿孔固持，避免只靠胶粘。

建议的1.5–2 mm非承力外壳壁厚、局部加强和打印孔补偿都只是首件输入，必须通过工艺样片修正。不能把螺钉拧紧程度当成消除轴承卡滞的方法。

## 7. 控制与工程集成

上游 MicroDuck 将嘴从其14维步态策略中分开，在 model.rs 中以0..1开口映射到原嘴关节的−5°..30°。[R3] 本方案借鉴“嘴单独控制”，不复用原角度范围或原机构。

Goose 保留一个主动嘴部控制量，但需换成新机构的开口/电机角映射。平行四连杆作为真实约束或经验证的等效机构建模；下喙被动压垫单独记录顺应性。物体保持自由接触，不使用焊接、瞬移或隐藏抓附。

动作顺序：预开口 → 低速接近 → 限流闭合 → 小幅试抬/确认 → 收颈搬运 → 放稳后张嘴。模式转换和夹力提升必须有上限；不能一旦识别到“有物体”就自动追求最大夹力。

两项厂商细节直接影响实现：

1. XL330的电流测量位于输入侧，与瞬态电机相电流不同；电流不是直接的夹持力传感器。必须建立“开口位置×电流×实际接触力”的台架标定。[R1]
2. 基于电流的位置模式不使用常规Min/Max Position Limit作为运动范围限制。控制端需要自己的角度/行程检查，机构也需要止挡；切模式后检查相关参数重置。[R1]

故障工况：不假定断电一定张嘴，也不保证掉电保住物体。设计可手动释放的机构维护路径；初样只在固定台架、低高度、非易碎物体上测试。软垫和限流不是儿童/宠物接触认证。

## 8. 验证顺序与放行条件

| 阶段 | 检查内容 | 建议放行口径 |
| --- | --- | --- |
| 真实包络CAD | 导入电机和相机尺寸；布置轴、法兰、齿轮、线材；全行程检查 | 30 mm级净开口可实现；无干涉；相机工作区未被新上喙不可接受地遮挡 |
| 无负载机构样件 | 开合、下喙姿态、间隙、左右同步 | 1000次开合无卡滞/松脱；记录姿态误差和磨耗，不只看能否动 |
| 定量夹持 | 分开测试拉环、杆件、块状物、薄边；测夹力与拉脱力 | 50 g指定物先测；之后100 g指定物；记录每种形状的成功率和失败方式 |
| 暂定重复性 | 每类指定物20次拾取与释放 | 初始研究门槛18/20；不据此推导通用抓取成功率 |
| 负载与热 | 指定物保持60 s、重复工作循环10 min | 电流/温升处在事先设定范围；无持续堵转、软垫撕裂或意外释放 |
| 颈部/全身 | 加入实测头嘴质量、抓取偏心和侧头姿态 | 独立验证可达、自碰撞和稳定性；嘴部台架不能代替这一步 |

必须单列失败情形：贴地薄片、光滑重物、无法进入的窄缝、明显偏心的长物体、湿滑接触、侧头角度不可达。

只有真实零件装配关系通过后，下一张外观图才可依据CAD生成。造型评审检查的是“固定上喙、平行下喙、窄尖和真实接触区”是否表达正确，而不是再次随机生成一张更厚的嘴。

## 9. 本轮已做与未做

已做：选定一条嘴部技术路线；定义几何/重量目标；查阅上游嘴部控制与厂商资料；计算理想连杆的开口、水平扫动、非共线裕量和简化力矩；列出增量物料、打印件和验证门槛。

未做：制造CAD、三维干涉分析、有限元、物理抓取仿真、真实打印装配、电机热测试或采购。任何目标值均不得标成实测。未改动Sai_Rotbots仓库、旧Excel或整机其他模块。

## 一手来源

[R1] ROBOTIS XL330-M288-T e-Manual  
https://emanual.robotis.com/docs/en/dxl/x/xl330-m288/  
尺寸、质量、输入电压、堵转扭矩、Current-based Position Control、电流测量位置、角度限位适用模式。

[R2] ROBOTIS America，XL330-M288-T  
https://robotis.us/products/dynamixel-xl330-m288-t  
查询时公开列价USD 27.49；页面库存显示不应等同中国可交付现货。其“额定”估计值由堵转扭矩百分比推算，未作为本机持续能力证据。

[R3] MicroDuck，duck-control/src/model.rs  
https://github.com/pollen-robotics/microduck/blob/main/duck-control/src/model.rs  
本轮读取blob：9de7d482f56205df107a4001ff5db08c1c27a8e8。嘴独立于14维策略；原嘴角度映射。本设计不照抄上游超出标准候选器件数据表的供电/保护设置。

[R4] Yale OpenHand  
https://www.eng.yale.edu/grablab/openhand/  
https://www.eng.yale.edu/grablab/openhand/model_m2.html  
被动柔顺/欠驱动接触的研究参考，不是Goose性能证明。未复制上游CAD。

[R5] igus，JFM-0304-03  
https://www.igus.bg/iglidur-ibh/flanged-bearings/product-details/iglidur-j-m?artnr=JFM-0304-03  
3 mm内径、4.5 mm外径、7.5 mm法兰外径、3 mm长度的候选衬套。需按实际安装和材料公差验证。

[R6] Smooth-On，Dragon Skin 20  
https://www.smooth-on.com/products/dragon-skin-20/  
Shore A20，1:1配比等以厂商资料为准；本材料的实际抓取摩擦系数没有测定。

[R7] ROBOTIS U2D2  
https://emanual.robotis.com/docs/en/parts/interface/u2d2/  
通信接口，不给DYNAMIXEL提供电机电源。

本方案参照已交付的《Goose_V0.1_Walker_Structure_and_BOM.md》，只替换嘴部。资料查询日期为2026-09-27，后续采购需再次确认型号、附件、库存与交期。

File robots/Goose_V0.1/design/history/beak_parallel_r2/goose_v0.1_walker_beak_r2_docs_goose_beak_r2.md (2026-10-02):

# Goose_V0.1 — 嘴部机械方案 R2
## 一体式鹅喙平行夹持机构

日期：2026-09-27  
配套版本：Walker / Beak R2 · 2026-09-27  
状态：方案设计、参数化运动示意与外观表达；不是制造 CAD 或实机验收。  
范围：替换步行鹅的嘴部机构及对应物料；已选定的身体、双足和颈部总体方向保持不变。

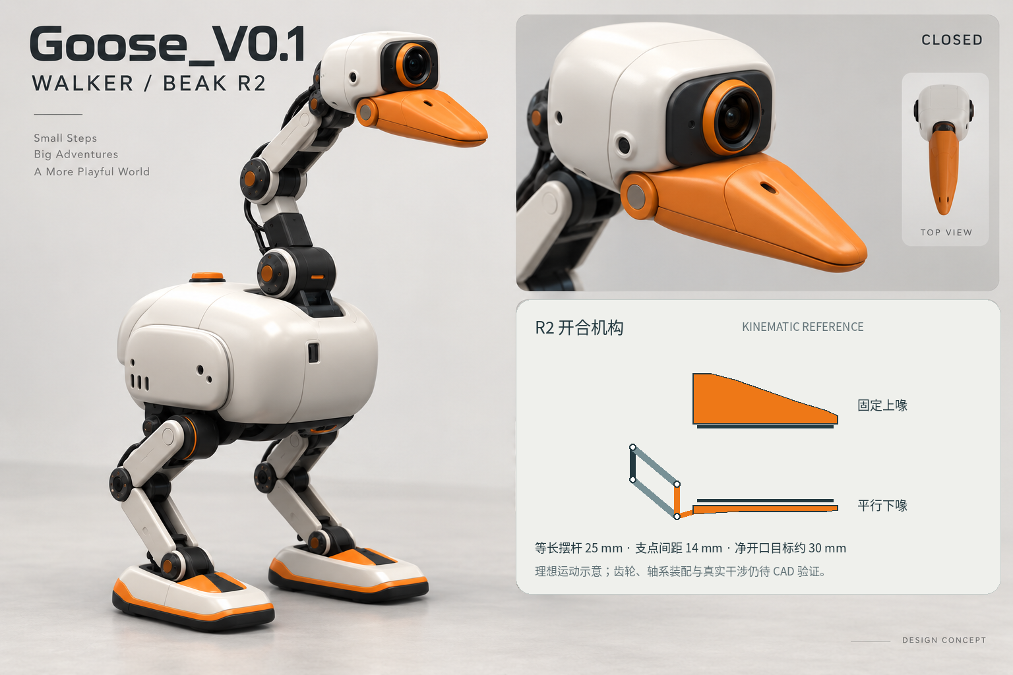
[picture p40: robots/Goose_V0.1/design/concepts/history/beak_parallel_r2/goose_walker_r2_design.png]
R2 方案效果图


[采购与打印工作簿](../../../hardware/history/beak_parallel_r2/goose_walker_r2_bom.xlsx) · [嘴部采购CSV](../../../hardware/history/beak_parallel_r2/beak_r2_purchase.csv)

## 1. 设计结论

采用“固定上喙 + 平行运动下喙 + 单舵机 + 嘴内柔顺接触垫”。
上下喙本身就是两片夹指，不在下巴外挂另一把夹爪。

外部轮廓和内部接触面分开设计：外部收尖、喙根较高、上背拱起，闭合时形成鹅嘴；内部设置相对的夹持面。灵活性由下喙运动轨迹、接触形状及现有头部滚转共同提供，不靠新增多台嘴部电机。

首轮目标是拾取指定轻物并可控释放。50 g 为第一阶段试验负载；100 g 为升级测试工况，不是适用于所有形状的额定载荷。鹅嘴台架通过不等于整机持物步行通过。

## 2. 造型规则

- 俯视从宽根渐收至窄、钝的前端，不做矩形前沿和全长等宽的鸭嘴板。
- 侧视上喙有高度和略拱的上背，下喙较浅，闭合后形成连续楔形；不使用猛禽式大钩尖。
- 上喙的高度来自空腔与加强筋，而非实心加厚。
- 深色部分只出现在口缝和口腔接触区；工作垫和机构不形成外伸的第三个夹爪。
- 相机仍装在固定头架上，不装在运动下喙上。上喙抬高后必须检查相机视锥，不能假定原视野不变。
- 两颊传动罩随真实零件包络设计；不得为了隐藏机构而随意放大整个鹅头。

以下是原型设计输入，不是由已有图片测得的尺寸：

| 参数 | 原型目标 |
| --- | --- |
| 外露喙长 | 约 60–65 mm |
| 橙色喙根宽 | 约 30–34 mm |
| 前端宽 | 约 12–14 mm，圆钝收尖 |
| 外露上/下喙闭合根部总高 | 约 26–30 mm；后方两颊机构空间单独检查 |
| 常用净开口 | 约 0–25 mm |
| 最大净开口目标 | 约 30 mm；理想运动行程约 32.1 mm |
| 可换接触垫厚 | 初试约 2 mm，按压缩量和保留结构调整 |
| 嘴部模块质量目标 | 不超过 65 g，包含嘴部电机、传动、支架、软垫与线材；不含相机、头壳和颈关节 |

嘴部重量必须独立称量，再与相机、头壳和头部关节合并形成颈部真实末端负载，不能把 65 g 当作整个头重。

## 3. 机构拓扑

### 3.1 固定部分

上喙固定在口部承力架上。承力架连接头部内框，并承接下喙的两个固定转轴。电机位于喙根后方，不放在嘴尖。

### 3.2 运动部分

采用竖向固定支点的平行四边形机构：

- 两个固定转轴在侧视中上下排列。
- 两根等长摆杆连接下喙后部的两个等间距转轴。
- 下喙与其后部立耳构成同一刚性连杆，因此理想运动时下喙姿态不变。
- 左右两侧各有两根摆杆，共四根；横向同轴支撑抑制偏心抓取造成的歪斜。
- 一台舵机经约 2:1 减速驱动一根固定转轴，四连杆约束其余运动。
- 两侧支撑的同轴度和轴向释放必须明确，避免打印公差使双侧机构卡滞。

这是让下喙本身运动的夹持机构，不是把成品平行夹爪塞进另一个鹅嘴外壳。

### 3.3 与普通张嘴铰链的差异

普通转动下喙的内表面会随开口倾斜，物体可能只受到边缘接触；斜接触还可能产生向外的分力。平行下喙的设计目的，是让有效接触面在不同开口下保持相对，减少对接触角度的依赖。软垫摩擦、物体形状和偏心力矩仍然需要验证。

代价是根部零件数量增加，而且下喙不是纯竖直移动。这些代价在本方案中显式保留，不称为“完美平行直线夹爪”。

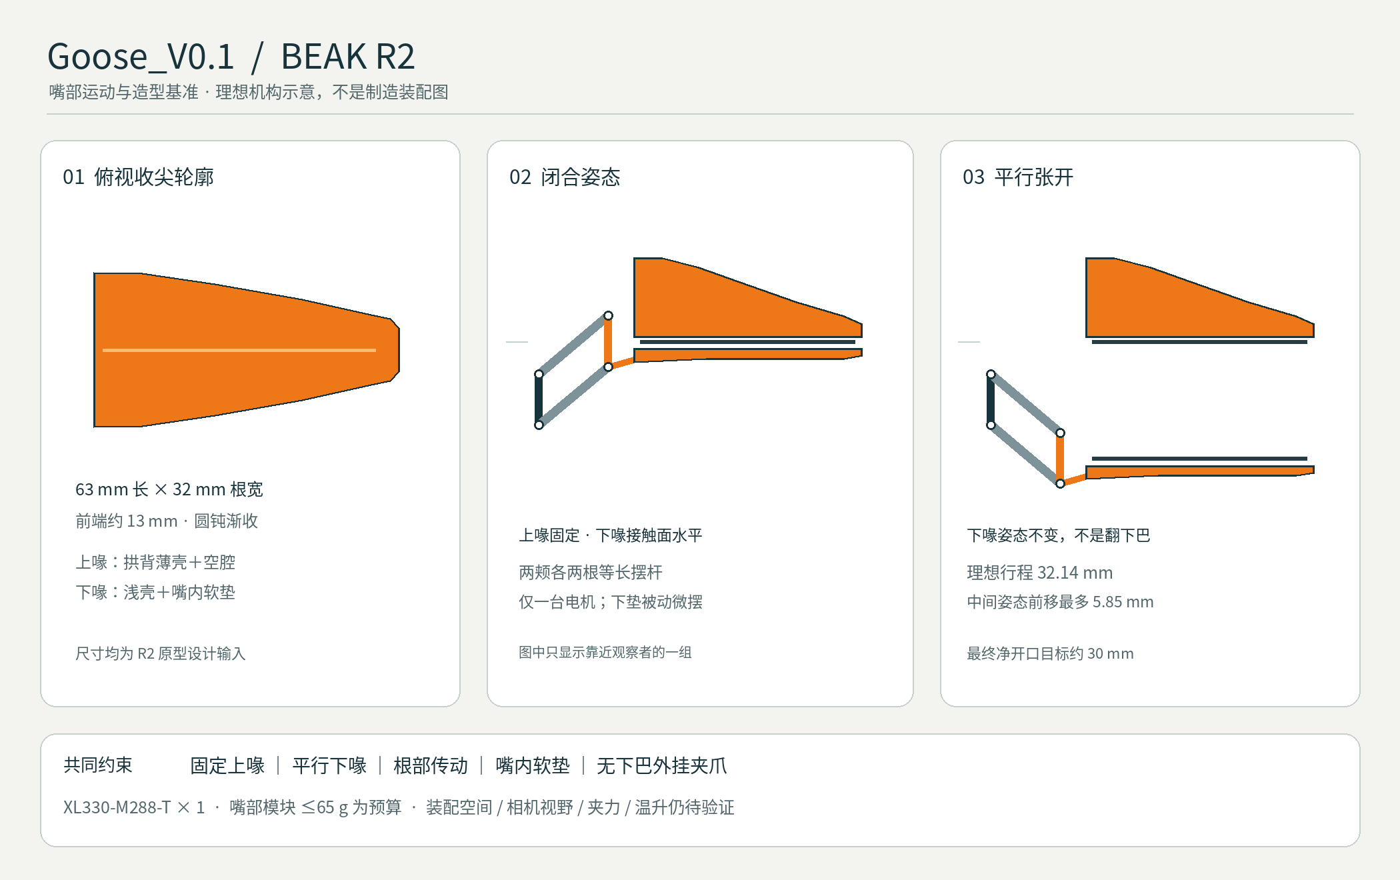
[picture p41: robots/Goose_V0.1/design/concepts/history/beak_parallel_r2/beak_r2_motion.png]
参数化运动示意


### 3.4 已计算的理想平面运动学

局部坐标：X 向前，Z 向上，转轴沿 Y。以下数字只是可行的初始参数组。

- 两根等长摆杆：L = 25 mm。
- 固定支点竖向间距：h = 14 mm；运动支点间距相同。
- 摆杆角度 q 相对 +X 测量。
- 闭合位置 q = +40°；张开位置 q = −40°。
- 舵机/摆杆角位移比 i = 2。

令 A=(0,0)、D=(0,h)，则：
B=(L cos q, L sin q)
C=B+(0,h)

理想下喙参考平面的开口变化：
g(q) = L [sin(40°) − sin(q)]

相对闭合位置的水平位移：
dx(q) = L [cos(q) − cos(40°)]

算例结果：

| 项目 | 结果 |
| --- | --- |
| 下喙理想开口行程 | 32.139 mm |
| 行程内最大前向偏移 | 5.849 mm |
| 全开与闭合的水平位置差 | 0 mm |
| 理想下喙姿态变化 | 0° |
| 2:1 减速下的舵机角行程 | 160° |
| 距离支点/摆杆共线的最近角度裕量 | 50° |

全行程没有经过这组理想连杆的共线位形，但这不等于三维零件不干涉。尚未验证齿轮、轴承法兰、连接螺钉、相机、护罩和上下喙之间的碰撞。

特别注意：闭合过程存在水平扫动，不能宣称夹点完全固定。需要降低接触阶段速度；对被固定物体，必要时用头部运动补偿。夹取自由物体时，要观察其是否被下喙推走。

2:1 只是传动比设计输入。齿数、模数、轴向错层和轴承安装必须由完整装配决定；14 mm 支点间距也允许为真实齿轮包络调整。不能直接把这组参数当作一张已解决全部装配的加工图。

## 4. 接触面，而非额外手指

### 4.1 同一副嘴的三个接触区

| 区域 | 几何和材料意图 | 首轮测试对象 |
| --- | --- | --- |
| 嘴尖前约 10–15 mm | 窄、相对的柔性接触面，前沿钝化 | 拉环、线绳、布条边缘、有可接近边缘的薄片 |
| 中段 | 浅 V 形软槽，初版按长条物沿嘴长方向定位 | 笔杆、短棒、轻型工具柄 |
| 靠近嘴根的内侧 | 较宽软垫和浅容纳凹区，不做闭合锁钩 | 指定小积木、轻型壳体、局部较厚的把手 |

这是同一副可换衬垫上的分区，不是三套末端工具，也不需要自动换嘴机构。

### 4.2 被动微顺应

下喙内放一个可拆压垫托，以小转轴和弹性回正件允许约 ±4° 的俯仰微调；设置硬限位，不允许整个嘴尖软塌。上喙使用固定柔性垫。

该被动角度不是新增主动自由度，不增加电机。目标是让偏斜的小物体获得更好的接触，而不是实现完整包络、灵巧手或已验证的“自适应抓取”。

Yale OpenHand 证明了被动柔顺和定制接触面是一条可研究的抓取路线；其手型、尺度和载荷不构成本方案性能证据，也不直接复制其非商业 CAD。[R4]

### 4.3 侧头抓取

利用已有 head_roll 候选轴改变夹持方向。侧头约 60–90° 可以把上下夹变成侧向夹的姿态意图，但头颈真实可达范围、自碰撞及线缆扭转必须验证；本轮不假定已经有 90° 可用行程。

侧头不能让下喙穿过桌面。贴地硬币、没有可接近边缘的薄纸、扁平贴合件，均不作为第一版必达对象。优先夹物体的边、把手或拉环，而不是要求嘴跨越整个大瓶身。

## 5. 驱动选型与载荷算例

### 5.1 首选样件

使用一台 ROBOTIS DYNAMIXEL XL330-M288-T：

- 官方尺寸 20 × 34 × 26 mm，重量 18 g。
- 推荐 5 V，允许输入 3.7–6.0 V。
- 支持电流控制和基于电流的位置控制。
- 5 V 下的 0.52 N·m 是堵转扭矩，不能当持续工作能力。[R1]

本轮保留这台电机，不默认增加第二台嘴部电机或更换全部关节驱动。选择的重点是重量、可采购来源、可查询控制表，以及与既有候选总线的衔接。

采购入口保留厂商产品页；本配套版不把上一轮的 USD 27.49 当作当前报价。价格、附件、库存及中国交付由供应商确认，采购分表单价留待询价。[R2]

### 5.2 100 g 对置摩擦夹持算例

假设：

- 物体质量 m = 0.10 kg；
- 向上加速度 a = 3 m/s²；
- 接触摩擦系数 μ = 0.4（假设，不是所选硅胶实测值）；
- 安全系数 S = 2；
- 两侧均有接触，每侧法向力为 N；
- 不计物体偏心转矩，仅计算滑落。

所需单侧法向力：
N ≥ S m(g+a)/(2μ) ≈ 3.203 N

因此可先将指定物体测试的法向夹力放在每侧约 2–4 N 的研究范围，按实际滑移、压痕和材料情况调整。这个范围不是人体接触安全标准。

对理想平行机构，在切向接触力可忽略的简化下：
τ_motor ≈ N L cos(q)/(i η)

取 i=2、假设传动效率 η=0.65，得到约 0.047–0.062 N·m。尚未加入下喙重量、轴系摩擦的不确定性、齿隙、斜向反力和冲击。这个算例支持进入台架测试，不证明电机长期可靠。

若存在切向力，应用完整雅可比项，而不是继续使用仅竖直力公式。嘴长不直接出现在上述纯平移功率关系里，也不意味着嘴长不影响刚度、轴系反力和偏心转矩。

### 5.3 质量分配

| 部分 | 预算 |
| --- | --- |
| 口部电机 | 18 g（厂商规格） |
| 上下喙、根部架、摆杆、传动件、压垫托 | 约 20–24 g 设计预算 |
| 轴、衬套、紧固件 | 约 8–10 g 设计预算 |
| 软垫、弹性回正件 | 约 4–6 g 设计预算 |
| 线材、固定附件及余量 | 约 5–7 g 设计预算 |
| 合计 | 约 55–65 g 的目标范围，不是称重结果 |

100 g 物体和约 60 g 嘴部模块，即便不算相机/头壳，在某颈关节前方 0.20 m 也会贡献约 0.314 N·m 静态重力矩。嘴夹验证通过后仍需重新核算颈部；不能把嘴夹能力等同于整机搬运能力。

## 6. 嘴部候选采购表

以下只列嘴部增量；已有主控、相机、IMU、电池和躯干不重复采购。未锁定安装孔位和长度的物料，不伪造最终发料数量。

| 项目 | 初样用量 | 规格/来源 | 采购或制造状态 |
| --- | --- | --- | --- |
| 嘴部舵机 | 1 个 | XL330-M288-T [R1][R2] | 可查询产品；先确认库存。旧样件可复用 |
| 舵盘/电机接口件 | 1 套 | 与 X330 实际输出接口匹配 | 用官方尺寸核对，不猜孔距 |
| 主连杆轴 | 4 根候选 | 直径 3 mm 精密光轴/肩轴 | 长度、轴向保留方式待装配；不用螺纹段当滑动轴面 |
| 主转轴衬套 | 8 个候选 | igus JFM-0304-03：内径3、外径4.5、法兰外径7.5、长3 mm [R5] | 按固定/运动轴的双侧支撑初配；压配孔需试样 |
| 压垫微摆轴 | 1 根候选 | 直径约2 mm金属轴 | 长度与止挡待压垫托定型 |
| 上下接触垫 | 装机2件，初试2副 | 约2 mm厚，Shore A20–30 硅胶试样 | 原型可裁切；分区形状用打印模具浇注 |
| 弹性回正件 | 1 组 | 同批硅胶/弹性体小件 | 从样料制作并测回正与迟滞 |
| 软垫浇注材料 | 1 小包装或加工服务 | Dragon Skin 20 为可查的 A20 候选 [R6] | 不是必买进口品牌；替代品需硬度/硫化资料与实测 |
| 螺钉、垫片、保留件 | 1 组 | M2为主，按X330和装配孔制式匹配 | 精确长度/数量由CAD导出 |
| 口部线材与应力释放 | 1 套 | 匹配所选舵机的原厂/验证线材 | 优先复用，不新增无必要供电体系 |
| 台架通信与5 V限流供电 | 已有则复用 | U2D2或现有兼容接口+独立合适电源 | U2D2只通信，不给舵机供电 [R7] |
| 夹力/拉脱力测试工具 | 1 套，已有则复用 | 小量程测力计或校准测力工装 | 这是台架工具，不是默认新增机载传感器 |

不对未报价打印件、轴系加工和中国交付成本给出虚构总价。

### 打印与加工件

| 零件 | 初样数量 | 制造要求 |
| --- | --- | --- |
| 上喙与固定安装结构 | 1 | 空腔+筋；相机视野检查 |
| 下喙刚性本体/后部连接架 | 1 | 夹面、轴孔和接触垫安装基准 |
| 根部左右支架/两颊罩 | 1套 | 电机、轴系、护罩运动间隙 |
| 等长摆杆 | 4 | 中心距一致；孔的加工/校准方法明确 |
| 约2:1传动齿轮 | 2 | 模数/齿数/厚度待真实包络；避开相邻轴与法兰 |
| 下喙微顺应压垫托 | 1 | ±4°候选止挡与回正件座 |
| 硅胶垫模具 | 1套 | 上下垫；脱模与机械锁扣/穿孔 |
| 台架安装座 | 1 | 固定头架，观察嘴部运动，不掩饰整机能力 |

第一轮可用 PETG 做装配和低载台架，承力件及齿轮的正式材料/工艺按寿命试验决定，PA12可列为加工候选。硅胶优先采用机械限位/穿孔固持，避免只靠胶粘。

建议的1.5–2 mm非承力外壳壁厚、局部加强和打印孔补偿都只是首件输入，必须通过工艺样片修正。不能把螺钉拧紧程度当成消除轴承卡滞的方法。

## 7. 控制与工程集成

上游 MicroDuck 将嘴从其14维步态策略中分开，在 model.rs 中以0..1开口映射到原嘴关节的−5°..30°。[R3] 本方案借鉴“嘴单独控制”，不复用原角度范围或原机构。

Goose 保留一个主动嘴部控制量，但需换成新机构的开口/电机角映射。平行四连杆作为真实约束或经验证的等效机构建模；下喙被动压垫单独记录顺应性。物体保持自由接触，不使用焊接、瞬移或隐藏抓附。

动作顺序：预开口 → 低速接近 → 限流闭合 → 小幅试抬/确认 → 收颈搬运 → 放稳后张嘴。模式转换和夹力提升必须有上限；不能一旦识别到“有物体”就自动追求最大夹力。

两项厂商细节直接影响实现：

1. XL330的电流测量位于输入侧，与瞬态电机相电流不同；电流不是直接的夹持力传感器。必须建立“开口位置×电流×实际接触力”的台架标定。[R1]
2. 基于电流的位置模式不使用常规Min/Max Position Limit作为运动范围限制。控制端需要自己的角度/行程检查，机构也需要止挡；切模式后检查相关参数重置。[R1]

故障工况：不假定断电一定张嘴，也不保证掉电保住物体。设计可手动释放的机构维护路径；初样只在固定台架、低高度、非易碎物体上测试。软垫和限流不是儿童/宠物接触认证。

## 8. 验证顺序与放行条件

| 阶段 | 检查内容 | 建议放行口径 |
| --- | --- | --- |
| 真实包络CAD | 导入电机和相机尺寸；布置轴、法兰、齿轮、线材；全行程检查 | 30 mm级净开口可实现；无干涉；相机工作区未被新上喙不可接受地遮挡 |
| 无负载机构样件 | 开合、下喙姿态、间隙、左右同步 | 1000次开合无卡滞/松脱；记录姿态误差和磨耗，不只看能否动 |
| 定量夹持 | 分开测试拉环、杆件、块状物、薄边；测夹力与拉脱力 | 50 g指定物先测；之后100 g指定物；记录每种形状的成功率和失败方式 |
| 暂定重复性 | 每类指定物20次拾取与释放 | 初始研究门槛18/20；不据此推导通用抓取成功率 |
| 负载与热 | 指定物保持60 s、重复工作循环10 min | 电流/温升处在事先设定范围；无持续堵转、软垫撕裂或意外释放 |
| 颈部/全身 | 加入实测头嘴质量、抓取偏心和侧头姿态 | 独立验证可达、自碰撞和稳定性；嘴部台架不能代替这一步 |

必须单列失败情形：贴地薄片、光滑重物、无法进入的窄缝、明显偏心的长物体、湿滑接触、侧头角度不可达。

本包全身与闭合嘴部效果用于方案外观沟通；主板右下角及独立运动示意由本节公式生成，二者均不是通过装配验证的制造CAD出图。制造级图纸须在真实零件装配、全行程与视野检查后导出。外观检查重点为固定上喙、平行下喙、收尖轮廓及口腔接触区。

## 9. 本轮已做与未做

已做：选定一条嘴部技术路线；定义几何/重量目标；查阅上游嘴部控制与厂商资料；计算理想连杆的开口、水平扫动、非共线裕量和简化力矩；列出增量物料、打印件和验证门槛。

本配套版新增方案效果图、参数化运动示意、工作区README，并同步整体结构文档与采购工作簿；所有嘴部表格采用同一份R2明细，整机18台候选执行器数量不变。

未做：制造CAD、三维装配干涉分析、有限元、物理抓取仿真、真实打印装配、电机热测试或采购。任何目标值均不得标成实测。未提交Sai_Rotbots仓库；原文件不覆盖，本包为新版本。

## 一手来源

[R1] ROBOTIS XL330-M288-T e-Manual  
https://emanual.robotis.com/docs/en/dxl/x/xl330-m288/  
尺寸、质量、输入电压、堵转扭矩、Current-based Position Control、电流测量位置、角度限位适用模式。

[R2] ROBOTIS America，XL330-M288-T  
https://robotis.us/products/dynamixel-xl330-m288-t  
产品与采购入口；本配套版不引用旧价格作为当前报价。未将由堵转百分比推算的值用作本机持续能力。

[R3] MicroDuck，duck-control/src/model.rs  
https://github.com/pollen-robotics/microduck/blob/main/duck-control/src/model.rs  
本轮读取blob：9de7d482f56205df107a4001ff5db08c1c27a8e8。嘴独立于14维策略；原嘴角度映射。本设计不照抄上游超出标准候选器件数据表的供电/保护设置。

[R4] Yale OpenHand  
https://www.eng.yale.edu/grablab/openhand/  
https://www.eng.yale.edu/grablab/openhand/model_m2.html  
被动柔顺/欠驱动接触的研究参考，不是Goose性能证明。未复制上游CAD。

[R5] igus，JFM-0304-03  
https://www.igus.cn/product/iglidur_J_FM  
3 mm内径、4.5 mm外径、7.5 mm法兰外径、3 mm长度的候选衬套。需按实际安装和材料公差验证。

[R6] Smooth-On，Dragon Skin 20  
https://www.smooth-on.com/products/dragon-skin-20/  
Shore A20，1:1配比等以厂商资料为准；本材料的实际抓取摩擦系数没有测定。

[R7] ROBOTIS U2D2  
https://emanual.robotis.com/docs/en/parts/interface/u2d2/  
通信接口，不给DYNAMIXEL提供电机电源。

本方案与本包《Goose_Walker_R2_Structure.md》配套，只替换嘴部。嘴部电机、衬套、软垫材料与U2D2官方资料于2026-09-27再次查阅；其余整机来源继承上一轮，采购仍需确认附件、库存、交期。

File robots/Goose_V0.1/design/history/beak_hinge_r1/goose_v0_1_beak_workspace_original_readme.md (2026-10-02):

# Goose_V0.1 工作区配套包

版本：beak_refinement_01 · 2026-09-27

## 放入工作区

将本包的 `robots/Goose_V0.1/` 合并到 Sai_Rotbots 工作区对应目录。
若工作区已有同名机器人 README，请合并导航链接，不覆盖原有内容。
本包根部的 README 只是移交说明，不复制为仓库根 README。

本轮核对的远端 catalog 仅登记 Sai_Agent_001 和 Sai_Agent_002。
`Goose_V0.1` 使用用户指定代号预排目录；接入实际模型时再按仓库规范正式登记，
不要为了导入设计图创建不存在的模型路径。登记来源：
https://github.com/sgyli7/Sai_Rotbots/blob/main/robots/catalog.json

## 内容

- 一张嘴部更新整机/细节概念板。
- 一份统一的结构、装配与验证说明，以及图像设计说明。
- 一个含「采购清单／打印加工／设计参数／来源」四页的 Excel。
- 与工作簿同版的采购、打印件 CSV，供 Agent 读取。

先打开 `robots/Goose_V0.1/README.md`。

## 交付边界

本包是新嘴部方案的配套设计资料，不是整机采购清单或可直接打印的CAD包。
文件间采用相同的单执行器、固定上喙/活动下喙及柔顺垫方案。
已报价条目、待报价项目、设计目标和厂商参数分别标明。
未写入远端 GitHub 或用户工作区。

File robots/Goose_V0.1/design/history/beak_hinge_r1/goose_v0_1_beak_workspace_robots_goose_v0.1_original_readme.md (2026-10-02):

# Goose_V0.1

B 步行鹅的嘴部更新设计包。版本：`beak_refinement_01`。

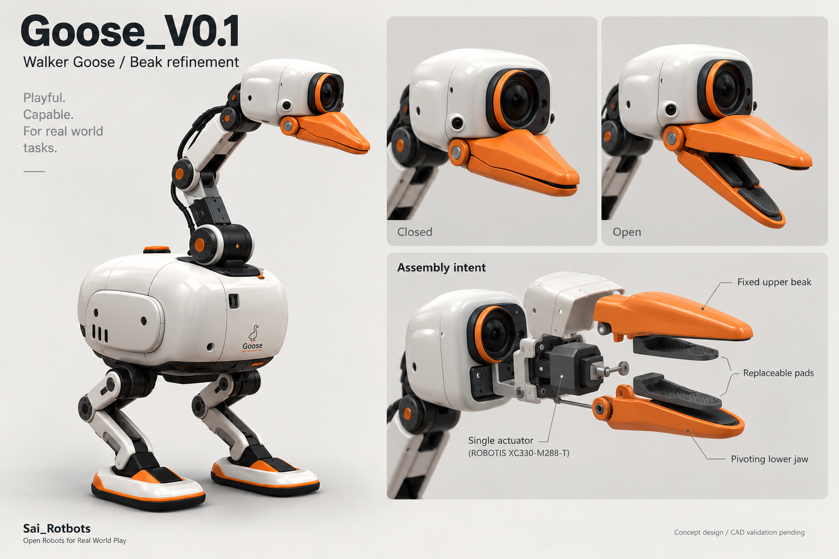
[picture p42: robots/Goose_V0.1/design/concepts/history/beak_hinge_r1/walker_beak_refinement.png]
Goose 嘴部更新


## 资料入口

| 资料 | 用途 |
|---|---|
| [嘴部结构与验证方案](goose_v0_1_beak_workspace_robots_goose_v0.1_design_beak_design.md) | 外形、机构、参数状态、装配及验证 |
| [效果图](../../concepts/history/beak_hinge_r1/walker_beak_refinement.png) | 整机视觉关系与嘴部细化 |
| [图像说明](goose_v0_1_beak_workspace_robots_goose_v0.1_design_concepts_beak_visual_brief.md) | 原图来源与视觉约束 |
| [采购工作簿](../../../hardware/history/beak_hinge_r1/beak_bom.xlsx) | 采购、打印件、参数及来源四页 |
| [采购 CSV](../../../hardware/history/beak_hinge_r1/beak_bom.csv) | 同版 BOM 的机器可读快照 |
| [打印件 CSV](../../../hardware/history/beak_hinge_r1/beak_print_parts.csv) | 同版打印加工分组 |

本版采用一个 XC330-M288-T 驱动单轴下喙，搭配固定上喙与一对可换柔顺垫。
身体、头壳、相机布局与步行鹅造型沿用已选方向。
当前交付状态为概念与结构候选，未完成制造 CAD 或实机验收。

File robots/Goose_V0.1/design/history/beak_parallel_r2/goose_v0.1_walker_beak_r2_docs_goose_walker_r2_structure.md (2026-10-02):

# Goose_V0.1 — 步行鹅结构与候选BOM（嘴部R2配套）

**日期：2026-09-27 · 方向：B / Walker Goose · 状态：外观已选定，硬件选型待验证**

本稿把选定造型拆成内部结构、关节、现成组件、打印加工件和采购入口。它不是制造图、完整装配包或已验证的整机BOM。“整机暂配数量”供结构占位与询价；“首批建议数量”供台架打样，不是采购指令。

## 1. 外观图与参数边界

Goose_V0.1 步行鹅 / 嘴部R2方案效果

[嘴部R2机械方案](goose_v0.1_walker_beak_r2_docs_goose_beak_r2.md) · [配套采购工作簿](../../../hardware/history/beak_parallel_r2/goose_walker_r2_bom.xlsx)

本次更新嘴部，其余沿用选定的白色圆润机身、长颈、两条机械腿及宽脚掌。方案效果图不含旧版未核算的尺寸、载荷或续航表。详细机构与数量以嘴部R2文档及对应采购分表为准。

**结构和选型以本文为准，不以图内自动生成的参数为准。**

| 项目 | 本稿采用的口径 |
| --- | --- |
| 每腿关节数 | 按MicroDuck参考的5轴研究，不使用图片的3轴标注。[S01] |
| 鹅颈 | 沿用首轮7R候选，嘴夹独立1轴。并未完成轴线、全工作空间、负载或布线验证。 |
| 高度、质量 | 图内55cm、6–8kg不是核算结果；最终尺寸由实物包络与质量/力矩闭环确定。 |
| 载荷、续航 | 图内0.2–0.5kg、2–4小时没有工程证据，不作为承诺。 |
| 计算单元 | 优先小型Radxa路线；Jetson不是默认必买件。 |
| 头部相机 | 先选RGB相机。单镜头外观不能据此称为双目/RGB-D；ToF另列可选件。 |
| 图上的“力控/自适应夹爪” | 当前落实为单轴开合、柔性接触垫、限流和机械限位的候选；没有力传感/夹持验证。 |

MicroDuck官方产品页标称25cm、780g、15个电机；其RL仓库将每腿5轴、颈头4轴写得明确，嘴夹独立控制。这是参照，不是把上游尺寸、负载或策略复制给Goose。[S01][S11]

## 2. 主要模块与内部结构

以下为本轮布置建议，不是从原图推导出的实际CAD内部装配。

| 模块 | 内部结构建议 | 功能与设计重点 |
| --- | --- | --- |
| 头部 | 轻型相机、镜头面板、头壳、嘴夹驱动及铰接支架 | 大镜头形成眼睛；相机略高于上嘴，实际测试地面工作区是否被嘴遮挡。 |
| 嘴夹 | 固定上喙、平行连杆下喙、单XL330、金属轴/衬套、嘴内软垫及被动微摆托 | 叼轻物、夹拉环、松开放置。嘴尖钝化；不是高力工业夹具。 |
| 鹅颈 | 7个候选旋转轴、连接支架、对侧支撑和护线结构 | 转头、点头、歪头、前探与收颈。要能转，也要有线缆余量和不自碰撞的空间。 |
| 躯干 | 承力内框、主控、USB/总线接口、电源分配、刚性固定IMU | 颈根和髋部的载荷传到内框，外壳主要保护与造型。 |
| 电池舱 | 低位电池托、锁止、连接器及绝缘 | 尽量靠近髋部，抽换不必拆头颈。位置最终由整机重心决定。 |
| 双腿 | 每腿髋偏航、髋侧摆、髋俯仰、膝俯仰、踝俯仰 | 髋侧摆负责横向移重；髋偏航辅助转向。不能只保留图片可见的前后屈伸轴。[S01] |
| 脚掌 | 刚性脚底板、可拆脚壳、软质底垫 | 既要支撑，也要检查摆腿时脚间碰撞、踝部干涉和脚尖离地。 |
| 线束与检修 | 分支线束、护线夹、可拆检修盖 | 颈部外观不能靠把线全部塞进没有空间的关节来实现。 |

**建议的内部层次：**

```text
头部：RGB相机 + 嘴夹（选配ToF）
              │ 活动线束与关节支撑
颈部：7R候选机构
              │
躯干上/中层：承力内框、Radxa主控、通信接口
躯干刚性区域：IMU（不是把活动头的姿态当成机身姿态）
躯干低位：电池与分支电源
              │
左腿5轴                右腿5轴
   │                       │
宽脚掌+软垫             宽脚掌+软垫
```

搬运姿态建议为收颈、低位持物、接近身体；停车后再伸颈。不假设加宽脚就能消除持物行走时的失稳。

## 3. 关节布局：暂按18个执行器研究

**双腿10 + 颈头7 + 嘴夹1 = 18。**

这是沿用首轮7R鹅颈的结构研究表，而不是已选中的成品机械臂。“12个XC330、6个XL330”只是便于零件包络、质量估算和询价的候选分配。对腿部、颈根甚至头部俯仰，都可能需要根据实测更换执行器。

| 关节名 | 部位 | 轴 | 作用 | 暂配候选 | 状态 |
| --- | --- | --- | --- | --- | --- |
| left_hip_yaw | 左腿 | 髋偏航 | 转向与摆脚方向 | XC330-M288-T | 待力矩/温升/冲击测试；仅轻量路线候选 |
| left_hip_roll | 左腿 | 髋侧摆 | 横向移重 | XC330-M288-T | 待力矩/温升/冲击测试；仅轻量路线候选 |
| left_hip_pitch | 左腿 | 髋俯仰 | 前后摆腿 | XC330-M288-T | 待力矩/温升/冲击测试；仅轻量路线候选 |
| left_knee_pitch | 左腿 | 膝俯仰 | 屈伸与下蹲 | XC330-M288-T | 待力矩/温升/冲击测试；仅轻量路线候选 |
| left_ankle_pitch | 左腿 | 踝俯仰 | 脚掌前后贴地角度 | XC330-M288-T | 待力矩/温升/冲击测试；仅轻量路线候选 |
| right_hip_yaw | 右腿 | 髋偏航 | 转向与摆脚方向 | XC330-M288-T | 待力矩/温升/冲击测试；仅轻量路线候选 |
| right_hip_roll | 右腿 | 髋侧摆 | 横向移重 | XC330-M288-T | 待力矩/温升/冲击测试；仅轻量路线候选 |
| right_hip_pitch | 右腿 | 髋俯仰 | 前后摆腿 | XC330-M288-T | 待力矩/温升/冲击测试；仅轻量路线候选 |
| right_knee_pitch | 右腿 | 膝俯仰 | 屈伸与下蹲 | XC330-M288-T | 待力矩/温升/冲击测试；仅轻量路线候选 |
| right_ankle_pitch | 右腿 | 踝俯仰 | 脚掌前后贴地角度 | XC330-M288-T | 待力矩/温升/冲击测试；仅轻量路线候选 |
| neck_base_yaw | 颈/头 | 颈根偏航 | 左右转向 | XL330-M288-T | 沿用首轮7R研究方案；轴线、负载与布线未冻结 |
| neck_base_pitch | 颈/头 | 颈根俯仰 | 整颈前探与抬起 | XC330-M288-T | 沿用首轮7R研究方案；轴线、负载与布线未冻结 |
| neck_twist | 颈/头 | 中段轴向扭转 | 改变弯折平面 | XL330-M288-T | 沿用首轮7R研究方案；轴线、负载与布线未冻结 |
| neck_mid_pitch | 颈/头 | 中段弯折 | 调节S形颈姿态 | XC330-M288-T | 沿用首轮7R研究方案；轴线、负载与布线未冻结 |
| head_yaw | 颈/头 | 头偏航 | 嘴朝向调整 | XL330-M288-T | 沿用首轮7R研究方案；轴线、负载与布线未冻结 |
| head_pitch | 颈/头 | 头俯仰 | 点头与夹取角度 | XL330-M288-T | 沿用首轮7R研究方案；轴线、负载与布线未冻结 |
| head_roll | 颈/头 | 头滚转 | 歪头与夹爪方向 | XL330-M288-T | 沿用首轮7R研究方案；轴线、负载与布线未冻结 |
| beak_open | 嘴夹 | 独立开合 | 固定上喙/平行下喙，约2:1传动 | XL330-M288-T | 需夹持力、开度、夹点与柔顺垫测试 |

## 4. 执行器候选：先比较两种，不一次混入多套生态

| 型号 | 厂商规格摘要 | 本轮用途 |
| --- | --- | --- |
| ROBOTIS XL330-M288-T | 18g，20×34×26mm，推荐5V；5V堵转扭矩0.52N·m；位置/速度/电流等反馈。[S03] | 轻载颈头轴及嘴夹的样件。 |
| ROBOTIS XC330-M288-T | 23g，同为20×34×26mm；推荐5V；5V堵转扭矩0.93N·m；金属齿轮。[S04] | 腿部与颈俯仰轴的轻量路线测试候选。 |

二者的**堵转扭矩不是可长期使用的持续扭矩**。同一外形/总线也不代表动力学、零点、控制参数可互换。尤其不能把这组小型执行器理解为已经可以支撑55cm、6–8kg的Goose。

例如仅有0.10kg物体、相对于某关节轴的水平力臂0.20m时，静态重力矩就约为 `0.10 × 9.81 × 0.20 = 0.196N·m`；这还不包括相机、嘴夹、连杆、电机自重和加速负载。该算式是示例，不是本机负载模型。

首批建议各拿2个进行台架测试：实测位置跟踪、摩擦/齿隙、保持温升及负载变化，再决定整机执行器。若不满足，要调整尺寸、重量、结构或电机，不靠超压驱动弥补。

## 5. 现成组件与采购入口

下表价格为上一轮整机记录，本配套版未逐项重新核价；不含税、物流、进口成本，库存与交期未确认。嘴部细目以配套工作簿“嘴部R2采购”为准，不能与整机父项叠加采购。空白单价保留为待询价。

| 编号 | 组件 | 候选型号/形式 | 整机暂配 | 首批建议 | 参考单价USD | 状态 | 放行条件 | 官方资料/采购入口 |
| --- | --- | --- | --- | --- | --- | --- | --- | --- |
| A01 | 腿部及重载颈轴执行器 | ROBOTIS XC330-M288-T | 12 个 | 2 个 | $103.39 | 先样件 | 先核算/实测持续力矩、步态速度、温升；不适用于已承诺的55cm/6–8kg整机 | [S04](https://emanual.robotis.com/docs/en/dxl/x/xc330-m288/) [S13](https://www.robotis.us/dynamixel-xc330-m288-t/) |
| A02 | 轻载颈头与嘴夹执行器 | ROBOTIS XL330-M288-T | 6 个 | 2 个 | 待询价 | 先样件 | 额外头颈质量需反算上游负载；完整7R尚未验证 | [S03](https://emanual.robotis.com/docs/en/dxl/x/xl330-m288/) |
| E01 | 机载主控 | Radxa ZERO 3W，建议2GB及板载eMMC版本 | 1 块 | 1 块 | 待询价 | 先样件 | 核对具体SKU、USB、电源、板卡尺寸与ONNX时延 | [S05](https://docs.radxa.com/en/zero/zero3) |
| E02 | 舵机通信转换器 | ROBOTIS U2D2 | 1 个 | 1 个 | $36.92 | 先样件 | 配置驱动/端口并实测读写时序；不能直接套原版串口程序 | [S06](https://emanual.robotis.com/docs/en/parts/interface/u2d2/) [S12](https://robotis.us/products/u2d2) |
| E03 | USB扩展 | 两口以上USB Hub，具体型号待选 | 1 个 | 1 个 | 待询价 | 待选型 | 同时验证UVC视频与串口；核对供电和反向灌电 | [S05](https://docs.radxa.com/en/zero/zero3) [S06](https://emanual.robotis.com/docs/en/parts/interface/u2d2/) [S07](https://www.arducam.com/arducam-usb-autofocus-imx219-b0292.html) |
| S01 | 头部主相机 | Arducam B0292 | 1 个 | 1 个 | $34.99 | 先样件 | 测试最近工作距离、夹爪遮挡、视频延迟与头部实重 | [S07](https://www.arducam.com/arducam-usb-autofocus-imx219-b0292.html) |
| S02 | 躯干IMU | SparkFun SEN-21336 / LSM6DSV16X | 1 块 | 1 块 | $25.50 | 先样件 | 需时间戳/姿态估计/驱动适配；非MicroDuck imu_to_dxl替换件 | [S08](https://www.sparkfun.com/sparkfun-micro-6dof-imu-breakout-lsm6dsv16x-qwiic.html) [S14](https://github.com/pollen-robotics/microduck/blob/main/docs/design/robotd-design.md) |
| S03 | 近距ToF（可选） | Pololu #3417 / VL53L5CX | 0 块 | 0 块 | $19.95 | 可选 | 先验证RGB方案；不等同精密抓取深度相机；3.3V主机需匹配I2C电平 | [S09](https://www.pololu.com/product/3417) |
| S04 | 状态灯与导光件 | 低功耗LED、驱动限流及打印导光结构 | 1 套 | 0 套 | 待询价 | 待选型 | 灯不与镜头混淆；具体电路和安装面待定 | 本轮结构建议 |
| S05 | 音频模块（可选） | 小扬声器+功放；麦克风仅按任务需要 | 0 套 | 0 套 | 待询价 | 可选 | 不属于抓取闭环的首批采购；型号和接口未选定 | 本轮结构建议 |
| P01 | 可拆电池包 | 带保护的成品电池包，串数/容量/接口待选 | 1 组 | 0 组 | 待询价 | 暂缓 | 按整机峰值/均方根电流与质量选型；NP-F外形不代表放电能力够用 | [S11](https://store.pollen-robotics.com/products/microduck) |
| P02 | 匹配充电器 | 与最终电芯化学体系及串数匹配的成品充电器 | 1 个 | 0 个 | 待询价 | 暂缓 | 电池SKU冻结后一起购买 | 本轮结构建议 |
| P03 | 整机电源分配 | 分支降压、保险、防反接、断电器件及连接器 | 1 套 | 0 套 | 待询价 | 待选型 | 各支路电流、线损、回灌和散热测试后才能下单 | [S03](https://emanual.robotis.com/docs/en/dxl/x/xl330-m288/) [S04](https://emanual.robotis.com/docs/en/dxl/x/xc330-m288/) |
| P04 | 降压模块台架候选 | Pololu D24V90F5 | 待定 块 | 1 块 | $36.82 | 先样件 | 不能以9A标题认定一块能带18舵机；不并联未知均流模块 | [S10](https://www.pololu.com/product/2866) |
| P05 | 运动电源切断组件 | 锁止按钮+适配直流负载的切断电路 | 1 套 | 1 套 | 待询价 | 待选型 | 按钮外形不是安全认证；断电会失去支撑，先在防坠台架测试 | 本轮结构建议 |
| C01 | DYNAMIXEL信号/电源线束 | X330对应X3P线、分支连接与应力释放 | 1 套 | 1 套 | 待询价 | 待选型 | 长度/线径/针序/压降待走线定稿；电机不带电插拔 | [S03](https://emanual.robotis.com/docs/en/dxl/x/xl330-m288/) [S04](https://emanual.robotis.com/docs/en/dxl/x/xc330-m288/) |
| C02 | 电池与电源线束 | 防反插连接器、软线、绝缘及固定件 | 1 套 | 1 套 | 待询价 | 待选型 | 连接器持续/峰值电流和弯折半径核对 | 本轮结构建议 |
| C03 | IMU与相机线束 | Qwiic 3.3V线、USB数据线与活动段软线 | 1 套 | 1 套 | 待询价 | 待选型 | I2C电平、USB弯折寿命、抗拉与插头尺寸验证 | [S05](https://docs.radxa.com/en/zero/zero3) [S07](https://www.arducam.com/arducam-usb-autofocus-imx219-b0292.html) [S08](https://www.sparkfun.com/sparkfun-micro-6dof-imu-breakout-lsm6dsv16x-qwiic.html) |
| M01 | 舵盘/从动支撑/连接件 | 与所选X330型号匹配的官方或验证过的支撑件 | 1 套 | 1 套 | 待询价 | 待选型 | 不能按概念图圆形关节直接选择圆形电机；核对附件清单 | [S03](https://emanual.robotis.com/docs/en/dxl/x/xl330-m288/) [S04](https://emanual.robotis.com/docs/en/dxl/x/xc330-m288/) |
| M02 | 金属轴/轴承/衬套 | 按CAD轴径与受力位置选型 | 1 套 | 1 套 | 待询价 | 待CAD | 未做轴系CAD前，不指定608等具体轴承尺寸 | 本轮结构建议 |
| M03 | 紧固件 | M2/M3螺钉、螺母、垫片与适配热熔嵌件 | 1 套 | 1 套 | 待询价 | 待CAD | 螺纹、长度、锁紧方式与数量待装配图，不强改厂商螺孔 | 本轮结构建议 |
| M04 | 可更换脚底垫 | 橡胶/硅胶片或经测试的TPU垫 | 2 片 | 2 片 | 待询价 | 先样件 | 测试摩擦、压缩、磨耗；非宽脚必然稳定 | 本轮结构建议 |
| M05 | 可更换嘴夹垫 | R2约2mm硅胶垫，Shore A20–30试样；三段接触区 | 2 片 | 4 片 | 待询价 | 先样件 | 摩擦/滑移/小物体夹持试验；不是经过验证的力控夹爪 | 本轮结构建议 |
| T01 | 限流稳压电源（测试工具） | 电压设为所选舵机工作点；带限流与保护 | 0 台 | 1 台 | 待询价 | 先样件 | 按测试电流选档；确认供电极性及超压保护 | [S03](https://emanual.robotis.com/docs/en/dxl/x/xl330-m288/) [S04](https://emanual.robotis.com/docs/en/dxl/x/xc330-m288/) [S06](https://emanual.robotis.com/docs/en/parts/interface/u2d2/) |
| T02 | 防坠与关节测试夹具（工具） | 台架/固定夹/承力支架 | 0 套 | 1 套 | 待询价 | 待CAD | 不得在整机演示中用隐藏支撑代替平衡能力 | [S02](https://github.com/sgyli7/Sai_Rotbots/blob/main/docs/OPEN_SOURCE_STATUS.md) |

### 采购清单里容易漏掉的实际连接件

USB相机与U2D2同时使用时，需要确认主控可用USB Host口，必要时加Hub；不是买齐三块板就自然能连接。[S05][S06][S07]

U2D2只负责通信，不给舵机供电。[S06] SparkFun IMU虽然采用与上游相关的LSM6DSV16X芯片，但它是通用I2C模块，不是MicroDuck原生`imu_to_dxl`板，需要自己的驱动、采样时间戳和姿态融合接口。[S08][S14]

舵盘、从动支撑、线材和螺钉是否随舵机附送，要逐SKU核对；最终需要哪些长度和数量，应由装配CAD导出，不靠效果图估计。

## 6. 可打印/可加工件目录

下表的软垫与采购表描述的是同一物料，不重复计价。材料是工艺候选，承力打印件必须测试层间方向、紧固和受力工况；不是指定材料后即可认定强度合格。

| 编号 | 零件组 | 暂配数量 | 单位 | 制造路线建议 | 结构重点 | 当前边界 |
| --- | --- | --- | --- | --- | --- | --- |
| F01 | 头壳与镜头面板 | 1 | 套 | PETG/ASA分体打印 | 相机可拆；镜头/USB插头包络；散热与碰撞保护 | 仅候选外观；尚无制造STL |
| F02 | 上嘴与下嘴刚性骨架 | 1 | 套 | 打印主体+金属铰接轴 | 固定上喙、平行下喙、双侧等长摆杆；嘴尖钝化；嘴内微顺应垫 | 夹持开度/连杆与负载待测试 |
| F03 | 嘴夹软垫 | 2 | 片 | 裁切橡胶/硅胶或TPU打印 | 机械卡位或螺固；避免脱落 | 与组件M05为同一物，不重复计价 |
| F04 | 颈段连接件与关节护罩 | 1 | 套 | 验证后的打印件；必要部位金属加强 | 7轴布置、双侧支撑、限位、线缆弯曲空间 | 护罩不代表已选中的电机外形 |
| F05 | 躯干外壳与检修盖 | 1 | 套 | 分体打印 | 主控/电池可独立拆；孔位在布置后生成 | 不含Cargo；不以渲染切面代替装配图 |
| F06 | 躯干承力内框 | 1 | 套 | 金属板件与验证后的打印支座 | 颈根/髋部力传到内框，外壳不作唯一承力件 | 壁厚、应力、紧固与跌落工况待定 |
| F07 | 腿部支架与对侧支撑 | 2 | 套 | 金属受力件/验证后的打印支架 | 每腿5轴；髋偏航和侧摆不能省略 | 轴线、无碰撞运动范围待CAD |
| F08 | 宽脚掌上壳与底板 | 2 | 只 | 刚性脚板+打印上壳 | 踝轴位置、脚间隙、脚底垫安装 | 不直接承诺不平地面/楼梯能力 |
| F09 | 脚底垫 | 2 | 片 | 裁切橡胶/硅胶或TPU打印 | 接地摩擦与微小缓冲 | 与组件M04为同一物，不重复计价 |
| F10 | 电池托与锁止件 | 1 | 套 | 打印+必要的金属锁止 | 低位装配，绝缘、防反插、能检修 | 电池型号冻结后制作 |
| F11 | 相机/IMU/主控安装架 | 1 | 套 | 小型打印支架+紧固件 | IMU刚性固定；相机光心可标定 | 没有额外第二IMU/力传感器默认需求 |
| F12 | 线夹/护线件/插头挡块 | 1 | 套 | 打印或采购标准件 | 连接器卸载与活动段抗拉 | 长度和位置由机构全行程检查确定 |

## 7. 供电与感知的接口约束

### 供电

拟采用“电池/台架电源 → 保护与分配 → 逻辑电源、执行器电源分支”的结构，具体容量、电流和降压模块数量待测试。这里不是可直接照接的电路图。

XL330-M288-T与XC330-M288-T的厂商允许输入范围均为3.7–6.0V、推荐5V。[S03][S04] 即便上游仿真配置出现不同电压，也不能据此把2S/3S电池原电压直接加到这些标准型号上。

Pololu D24V90F5是可测试的5V支路候选，而不是已经选定的整机电源。厂商说明实际持续电流受热条件影响，不能将标题中的“9A”直接用于18舵机整机保证。[S10] 未验证均流的输出不能简单并联；回灌、负载跃变、线损及限流都应验证。

停止运动与切断执行器供电需要区分。双足断电会失去主动支撑；先在防坠台架验证故障处理，不能把图上的橙色按钮称为已经实现的安全急停系统。

### 相机与嘴夹

B0292是RGB相机候选，不是RGB-D。[S07] 需要实际测试嘴尖工作距离、镜头近焦范围、抓物时遮挡和延迟。选配VL53L5CX只增加8×8测距，不等同高分辨率三维抓取相机。[S09]

嘴部R2保持一个主动输入，经约2:1传动带动平行下喙；增加嘴内分区软垫、被动微摆托、限流及机械止挡。电流反馈只能辅助判断受力，不能当成经过标定的夹持力传感器；瓶子、杯子、柔软织物、细拉环应分开测试。

## 8. 和既有工程的衔接

MicroDuck的每腿5轴、50Hz策略循环、执行器建模与ONNX导出规则值得参考；50Hz是策略/控制频率，不能直接当作所有物理仿真的步进频率。[S01]

Goose的拟议18执行器结构与原MicroDuck的15执行器不同。原14维策略动作和61维观测不会因为外形相近就自动适配。需要独立的关节顺序、坐标/限位、惯量与执行器参数，再确定观测和动作契约。[S01]

Sai_Rotbots中的模型/控制/来源记录方法可以沿用，但其既有轮腿机器人质量、阶梯成绩、仿真扭矩上限和100g任务证据，不是Goose的硬件证明。[S02]

## 9. 当前可执行的采购边界

现在适合采购的是：两类执行器样件、通信接口、主控/相机/IMU，以及测试供电、线材、软垫和台架。首先解决“头嘴实重 → 颈部负载 → 单腿关节负载”这条链。

整机18个执行器、最终电池、电源分配、承力内框、完整壳体和全部螺钉暂不批量下单。它们需要在实物尺寸、力矩/热测试及CAD装配之后释放。

本配套版同步了整体结构、嘴部方案与采购工作簿。没有完成制造CAD、整机仿真训练、实机步行、采购、订单提交或仓库修改。

## 一手来源

**[S01] MicroDuck RL / 关节布局与训练约定**  
https://github.com/pollen-robotics/microduck_rl/blob/develop/README.md  
每腿5关节；颈头4关节；14维动作，嘴夹独立；50 Hz策略。读取文件blob：7575f9baf33db3dd2bee7131e3b1e212d54ccac1。

**[S02] Sai_Rotbots / 硬件成熟度**  
https://github.com/sgyli7/Sai_Rotbots/blob/main/docs/OPEN_SOURCE_STATUS.md  
仿真alpha；未完成制造、实机持续力矩与热验证。读取文件blob：7a5951295e3b6736f09498e677ce3a5f656ca0f0。

**[S03] ROBOTIS XL330-M288-T e-Manual**  
https://emanual.robotis.com/docs/en/dxl/x/xl330-m288/  
18 g；20×34×26 mm；3.7–6.0 V，推荐5 V；0.52 N·m@5 V为堵转扭矩。

**[S04] ROBOTIS XC330-M288-T e-Manual**  
https://emanual.robotis.com/docs/en/dxl/x/xc330-m288/  
23 g；20×34×26 mm；3.7–6.0 V，推荐5 V；0.93 N·m@5 V为堵转扭矩；金属齿轮。

**[S05] Radxa ZERO 3 官方文档**  
https://docs.radxa.com/en/zero/zero3  
RK3566，65×30 mm；USB接口、电源、存储选项以具体板卡版本为准。

**[S06] ROBOTIS U2D2 e-Manual**  
https://emanual.robotis.com/docs/en/parts/interface/u2d2/  
USB到DYNAMIXEL通信接口；不向舵机供电。

**[S07] Arducam B0292 官方产品页**  
https://www.arducam.com/arducam-usb-autofocus-imx219-b0292.html  
8MP A219/IMX219系列自动对焦USB UVC相机；官方页面参考价USD 34.99。不是深度相机。

**[S08] SparkFun SEN-21336 / LSM6DSV16X**  
https://www.sparkfun.com/sparkfun-micro-6dof-imu-breakout-lsm6dsv16x-qwiic.html  
Micro Qwiic IMU；19.05×7.62 mm；3.3 V接口路线；官方页面参考价USD 25.50。不是MicroDuck原生DYNAMIXEL IMU板。

**[S09] Pololu #3417 / VL53L5CX**  
https://www.pololu.com/product/3417  
8×8 ToF测距；13×18×3 mm；裸板0.5 g；官方页面参考价USD 19.95。非完整RGB-D。

**[S10] Pololu #2866 / D24V90F5**  
https://www.pololu.com/product/2866  
5 V降压模块，标题9 A；持续电流取决于热条件，页面给出典型4–8 A范围；官方参考价USD 36.82。

**[S11] MicroDuck 官方产品页**  
https://store.pollen-robotics.com/products/microduck  
官方标称25 cm、780 g、15电机、RK3566、相机/ToF；仅用于参照，不是Goose规格。

**[S12] ROBOTIS U2D2 官方商店**  
https://robotis.us/products/u2d2  
官方页面参考价USD 36.92；库存/交期需确认。

**[S13] ROBOTIS XC330-M288-T 官方商店**  
https://www.robotis.us/dynamixel-xc330-m288-t/  
检索显示参考价USD 103.39；价格为公开页面快照，非含税到手报价，采购前复核。

**[S14] MicroDuck robotd / 原生硬件接口**  
https://github.com/pollen-robotics/microduck/blob/main/docs/design/robotd-design.md  
原生15舵机与imu_to_dxl v2共用串口总线；通用I2C IMU及U2D2需适配，不是原版软件即插即用。

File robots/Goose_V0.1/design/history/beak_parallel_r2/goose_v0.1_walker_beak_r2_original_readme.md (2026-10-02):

# Goose_V0.1 / Walker · Beak R2

**2026-09-27 · 方案效果与工程说明配套包**

步行鹅身体和双足沿用已选方向；嘴部采用固定上喙、平行运动下喙、单台 XL330-M288-T、嘴内柔顺垫及被动微摆。上下喙本身就是夹指，头部滚转负责改变抓取方向。

R2方案效果图

## 文件入口

| 文件 | 用途 |
|---|---|
| [R2设计效果图](../../concepts/history/beak_parallel_r2/goose_walker_r2_design.png) | 当前全身与闭合嘴部效果；开合小图使用公式化示意 |
| [嘴部运动示意](../../concepts/history/beak_parallel_r2/beak_r2_motion.png) | 由R2公式生成；平行下喙、收尖轮廓、理想开口和前向扫动 |
| [嘴部机械说明](goose_v0.1_walker_beak_r2_docs_goose_beak_r2.md) | 机构、尺寸/质量目标、执行器、接触区、控制与验证 |
| [整体结构说明](goose_v0.1_walker_beak_r2_docs_goose_walker_r2_structure.md) | 主控、相机、躯干、双腿、供电与嘴部的关联；已同步R2 |
| [采购工作簿](../../../hardware/history/beak_parallel_r2/goose_walker_r2_bom.xlsx) | 保留整机候选，新增嘴部采购、嘴部打印、R2可复算参数分表 |
| [嘴部采购CSV](../../../hardware/history/beak_parallel_r2/beak_r2_purchase.csv) | 便于工作区脚本/Agent读取，与工作簿同源 |
| [嘴部打印件CSV](../../../hardware/history/beak_parallel_r2/beak_r2_print_parts.csv) | 零件目录与加工放行条件，与工作簿同源 |

## 当前设计基线

| 项目 | R2输入 |
|---|---|
| 喙形 | 根部较高、上背略拱、俯视收尖、前缘圆钝；不采用平板鸭嘴 |
| 驱动 | 一台XL330-M288-T；约2:1减速；无额外嘴部电机 |
| 下喙 | 双侧平行四边形连杆约束姿态；不是普通大角度下巴铰链 |
| 夹持垫 | 同一副垫的窄尖/浅V槽/近根持物区；下垫约±4°被动微摆 |
| 几何目标 | 外露喙长60–65mm、根宽30–34mm、尖宽12–14mm；净开口目标约30mm |
| 质量预算 | 嘴部模块≤65g，含嘴部电机；不含相机、头壳和颈轴 |
| 全机执行器 | 仍是候选18台；本次嘴部1台已包含于整机A02，不能重复计数 |

## 工作区使用

解压后保留文件夹内部相对路径。可把整个目录放在 `Sai_Rotbots/Goose_V0.1/Design_R2/`，无需改动现有项目。

后续执行以 **嘴部R2机械说明与工作簿 → 整体结构说明 → 效果图** 的顺序理解；效果图不定义隐藏机构、孔位、惯量或性能。制造前先完成真实电机/相机包络装配、全行程干涉、视野与走线，再做单嘴台架；关节与物体均使用真实接触，不以隐藏抓附代替夹持。

**交付范围：**本包包含方案效果图、参数化运动示意、说明与候选物料；没有制造CAD、可直接打印的STL或实机验收结果。旧的55cm、6–8kg、2–4小时等图内数字不是当前规格。整机表中的价格为上一轮记录，嘴部新采购价格待询。

没有向GitHub提交文件，也没有进行采购。原始资料保持不变，此目录为配套新版本。

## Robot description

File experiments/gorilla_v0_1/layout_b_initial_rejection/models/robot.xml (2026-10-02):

<mujoco model="gorilla_layout_b">
  <compiler angle="radian" autolimits="true" inertiafromgeom="false" meshdir="assets" />
  <option timestep=".002" gravity="0 0 -9.81" integrator="implicitfast" iterations="100" tolerance="1e-10" />
  <default>
    <joint limited="true" damping="2" armature="0" />
    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
  </default>
  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
  <worldbody>
    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
    <body name="pelvis" pos="0 0 1.6">
      <freejoint name="floating_root" />
      <body name="waist_yaw_link" pos="0 0 0.14">
        <joint name="waist_yaw" type="hinge" axis="0 0 1" range="-0.6 0.6" />
        <body name="waist_pitch_link" pos="0 0 0">
          <joint name="waist_pitch" type="hinge" axis="0 1 0" range="-0.35 0.55" />
          <body name="torso" pos="0 0 0">
            <joint name="waist_roll" type="hinge" axis="1 0 0" range="-0.25 0.25" />
            <body name="left_shoulder_pitch_link" pos="-0.05 0.62 0.55">
              <joint name="left_shoulder_pitch" type="hinge" axis="0 1 0" range="-2 1.2" />
              <body name="left_shoulder_roll_link" pos="0 0 0">
                <joint name="left_shoulder_roll" type="hinge" axis="1 0 0" range="-1.2 1.2" />
                <body name="left_upper_arm" pos="0 0 0">
                  <joint name="left_shoulder_yaw" type="hinge" axis="0 0 1" range="-1.2 1.2" />
                  <body name="left_forearm" pos="0.08 0.16 -0.5">
                    <joint name="left_elbow_pitch" type="hinge" axis="0 1 0" range="-1.5 1.1" />
                    <body name="left_wrist_yaw_link" pos="0.015 0.01 -0.6">
                      <joint name="left_wrist_yaw" type="hinge" axis="0 0 1" range="-1 1" />
                      <body name="left_wrist_pitch_link" pos="0 0 0">
                        <joint name="left_wrist_pitch" type="hinge" axis="0 1 0" range="-0.8 0.8" />
                        <body name="left_palm" pos="0 0 0">
                          <joint name="left_wrist_roll" type="hinge" axis="1 0 0" range="-0.8 0.8" />
                          <body name="left_finger_1_proximal_link" pos="0.065 -0.102 -0.22">
                            <joint name="left_finger_1_proximal" type="hinge" axis="0 1 0" range="0 1.15" />
                            <body name="left_finger_1_distal_link" pos="0 0 -0.095">
                              <joint name="left_finger_1_distal" type="hinge" axis="0 1 0" range="0 1.3" />
                              <inertial pos="0.00231999579893 2.58126853225e-13 -0.00572265643048" mass="0.957426961802" fullinertia="0.00103485478946 0.000926294985518 0.000864059705223 2.26295271157e-08 8.28595001484e-05 9.17411939302e-09" />
                              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
                            </body>
                            <inertial pos="0.00309843222078 0 -0.0119961868807" mass="1.09885301901" fullinertia="0.0015110653078 0.00146138534086 0.00105790478705 2.26151211594e-08 0.00010555935221 -6.93889390391e-18" />
                            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
                          </body>
                          <body name="left_finger_2_proximal_link" pos="0.065 0 -0.22">
                            <joint name="left_finger_2_proximal" type="hinge" axis="0 1 0" range="0 1.15" />
                            <body name="left_finger_2_distal_link" pos="0 0 -0.095">
                              <joint name="left_finger_2_distal" type="hinge" axis="0 1 0" range="0 1.3" />
                              <inertial pos="0.00231999579893 2.58126853225e-13 -0.00572265643048" mass="0.957426961802" fullinertia="0.00103485478946 0.000926294985518 0.000864059705223 2.26295271263e-08 8.28595001484e-05 9.17411932312e-09" />
                              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
                            </body>
                            <inertial pos="0.00309843222078 2.22044604925e-16 -0.0119961868807" mass="1.09885301901" fullinertia="0.0015110653078 0.00146138534086 0.00105790478705 2.26151211655e-08 0.00010555935221 9.87132406231e-17" />
                            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
                          </body>
                          <body name="left_finger_3_proximal_link" pos="0.065 0.102 -0.22">
                            <joint name="left_finger_3_proximal" type="hinge" axis="0 1 0" range="0 1.15" />
                            <body name="left_finger_3_distal_link" pos="0 0 -0.095">
                              <joint name="left_finger_3_distal" type="hinge" axis="0 1 0" range="0 1.3" />
                              <inertial pos="0.00231999579893 2.58015830923e-13 -0.00572265643048" mass="0.957426961802" fullinertia="0.00103485478946 0.000926294985518 0.000864059705223 2.2629527125e-08 8.28595001484e-05 9.17411936374e-09" />
                              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
                            </body>
                            <inertial pos="0.00309843222078 -1.11022302463e-16 -0.0119961868807" mass="1.09885301901" fullinertia="0.0015110653078 0.00146138534086 0.00105790478705 2.26151211548e-08 0.00010555935221 5.338020037e-17" />
                            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
                          </body>
                          <body name="left_thumb_proximal_link" pos="0.055 -0.175 -0.08">
                            <joint name="left_thumb_proximal" type="hinge" axis="1 0 0" range="0 1.15" />
                            <body name="left_thumb_distal_link" pos="0.005 0.035 -0.095">
                              <joint name="left_thumb_distal" type="hinge" axis="1 0 0" range="0 1.3" />
                              <inertial pos="0.00290447568372 0.00191083931174 -0.0051974827753" mass="0.958510415118" fullinertia="0.00087620990969 0.0010585787342 0.00090645724758 -3.56666172401e-05 9.35933702642e-05 6.3855388656e-05" />
                              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
                            </body>
                            <inertial pos="0.00053829878165 0.00376809151138 -0.0102276767517" mass="1.04401803612" fullinertia="0.00138381733589 0.00148901278412 0.00106770278982 -9.44167494933e-06 2.43620240523e-05 0.000179568495008" />
                            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
                          </body>
                          <inertial pos="0.0126077654672 -1.11022302463e-16 -0.0421086297988" mass="9.5345553695" fullinertia="0.0943717346322 0.0802592714939 0.0633885595798 -2.4155877925e-06 0.00899019246205 -9.39812312352e-16" />
                          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
                        </body>
                        <inertial pos="-6.93889390391e-18 0 -2.22044604925e-16" mass="6.1" fullinertia="0.01964390625 0.0207590625 0.01964390625 0 -9.39853812861e-33 0" />
                      </body>
                      <inertial pos="-6.93889390391e-18 0 -2.22044604925e-16" mass="6.1" fullinertia="0.01964390625 0.01964390625 0.0207590625 0 -9.39853812861e-33 0" />
                    </body>
                    <inertial pos="0.00298280776583 0.00917999578177 -0.107176724624" mass="22.2486199756" fullinertia="0.805593418132 0.804776526039 0.259228840677 -0.00142021814287 0.0143723643648 0.0422497088924" />
                    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
                  </body>
                  <inertial pos="0.00605261947207 0.0603525166354 -0.108315018843" mass="15.7573653879" fullinertia="0.541312196851 0.514236580759 0.221891926532 -0.00527112223704 0.0513257063007 0.0860762579977" />
                  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
                </body>
                <inertial pos="-6.93889390391e-18 -1.11022302463e-16 0" mass="14.2" fullinertia="0.08591 0.0834545833333 0.0834545833333 -1.09392820841e-32 0 0" />
              </body>
              <inertial pos="-6.93889390391e-18 -1.11022302463e-16 0" mass="14.2" fullinertia="0.0834545833333 0.08591 0.0834545833333 -1.09392820841e-32 0 0" />
            </body>
            <body name="right_shoulder_pitch_link" pos="-0.05 -0.62 0.55">
              <joint name="right_shoulder_pitch" type="hinge" axis="0 1 0" range="-2 1.2" />
              <body name="right_shoulder_roll_link" pos="0 0 0">
                <joint name="right_shoulder_roll" type="hinge" axis="1 0 0" range="-1.2 1.2" />
                <body name="right_upper_arm" pos="0 0 0">
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

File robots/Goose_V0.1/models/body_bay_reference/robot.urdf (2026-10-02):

<robot name="goose_body_bay_reference_si_v1">
  <link name="world" />
  <joint name="root" type="floating">
    <parent link="world" />
    <child link="torso" />
    <origin xyz="0 0 0" rpy="0 0 0" />
  </joint>
  <link name="torso">
    <inertial>
      <origin xyz="-0.014192751185813823 -0.0017329935524373985 0.32991239544524614" rpy="0 0 0" />
      <mass value="2.1465136455389726" />
      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
    </inertial>
    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
  </link>
  <joint name="neck_yaw" type="revolute">
    <parent link="torso" />
    <child link="neck_yaw" />
    <origin xyz="0.042999999999999997 0 0.34570000000000001" rpy="0 0 0" />
    <axis xyz="0 0 1" />
    <limit lower="-0.5" upper="0.5" effort="2.0" velocity="38.746309394274114" />
    <dynamics damping="0.01" friction="0.03" />
  </joint>
  <link name="neck_yaw">
    <inertial>
      <origin xyz="-1.1827472334857703e-10 -0.0022249624644583746 0.061557805242292096" rpy="0 0 0" />
      <mass value="0.4329192720569949" />
      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
    </inertial>
    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
  </link>
  <joint name="neck_pitch" type="revolute">
    <parent link="neck_yaw" />
    <child link="neck_pitch" />
    <origin xyz="0 0 0.065999999999999948" rpy="0 0 0" />
    <axis xyz="0 1 0" />
    <limit lower="-0.6" upper="2.6" effort="12.0" velocity="4.1887902047863905" />
    <dynamics damping="0.01" friction="0.4" />
  </joint>
  <link name="neck_pitch">
    <inertial>
      <origin xyz="-0.05799548597643267 -0.00090780865849446031 0.081857880153021478" rpy="0 0 0" />
      <mass value="0.6107350780492311" />
      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
    </inertial>
    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
  </link>
  <joint name="neck_mid_pitch" type="revolute">
    <parent link="neck_pitch" />
    <child link="neck_mid_pitch" />
    <origin xyz="-0.072999999999999995 0 0.10400000000000009" rpy="0 0 0" />
    <axis xyz="0 1 0" />
    <limit lower="-1.4" upper="1.4" effort="12.0" velocity="4.1887902047863905" />
    <dynamics damping="0.01" friction="0.4" />
  </joint>
  <link name="neck_mid_pitch">
    <inertial>
      <origin xyz="0.052393753795951604 0.0020634254785762882 0.067520416219901236" rpy="0 0 0" />
      <mass value="0.5145364404531154" />
      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
    </inertial>
    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
  </link>
  <joint name="head_pitch" type="revolute">
    <parent link="neck_mid_pitch" />
    <child link="head_pitch" />
    <origin xyz="0.072000000000000008 0 0.092999999999999972" rpy="0 0 0" />
    <axis xyz="0 1 0" />
    <limit lower="-1.6" upper="1.6" effort="4.0" velocity="12.56637061435917" />
    <dynamics damping="0.01" friction="0.05" />
  </joint>
  <link name="head_pitch">
    <inertial>
      <origin xyz="0.029758710579607779 -9.8705722209677163e-19 -0.014214247255787238" rpy="0 0 0" />
      <mass value="0.06518204602470656" />
      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
    </inertial>
    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
  </link>
  <joint name="head_roll" type="revolute">
    <parent link="head_pitch" />
    <child link="head_roll" />
    <origin xyz="0.039 0 -0.019499999999999962" rpy="0 0 0" />
    <axis xyz="1 0 0" />
    <limit lower="-0.6" upper="0.6" effort="0.18" velocity="3.0" />
    <dynamics damping="0.01" friction="0.006" />
  </joint>
  <link name="head_roll">
    <inertial>
      <origin xyz="0.056652098479449256 0.0010933478216618644 0.010315910456322408" rpy="0 0 0" />
      <mass value="0.6467862136785603" />
      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
    </inertial>
    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
  </link>
  <joint name="beak_hinge" type="revolute">
    <parent link="head_roll" />
    <child link="beak_hinge" />
    <origin xyz="0.079000000000000001 0 -0.0095000000000000639" rpy="0 0 0" />
    <axis xyz="0 1 0" />
    <limit lower="0.0" upper="0.55" effort="4.5" velocity="1.0" />
    <dynamics damping="0.01" friction="0.08" />
  </joint>
  <link name="beak_hinge">
    <inertial>
      <origin xyz="0.019171693409097884 0.0021173250088120988 -0.013640486731100299" rpy="0 0 0" />
      <mass value="0.06762954187560048" />
      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
    </inertial>
    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
  </link>
  <joint name="right_hip_yaw" type="revolute">
    <parent link="torso" />
    <child link="right_hip_yaw" />
    <origin xyz="-0.017999999999999999 -0.065000000000000002 0.3387" rpy="0 0 0" />
    <axis xyz="0 0 1" />
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

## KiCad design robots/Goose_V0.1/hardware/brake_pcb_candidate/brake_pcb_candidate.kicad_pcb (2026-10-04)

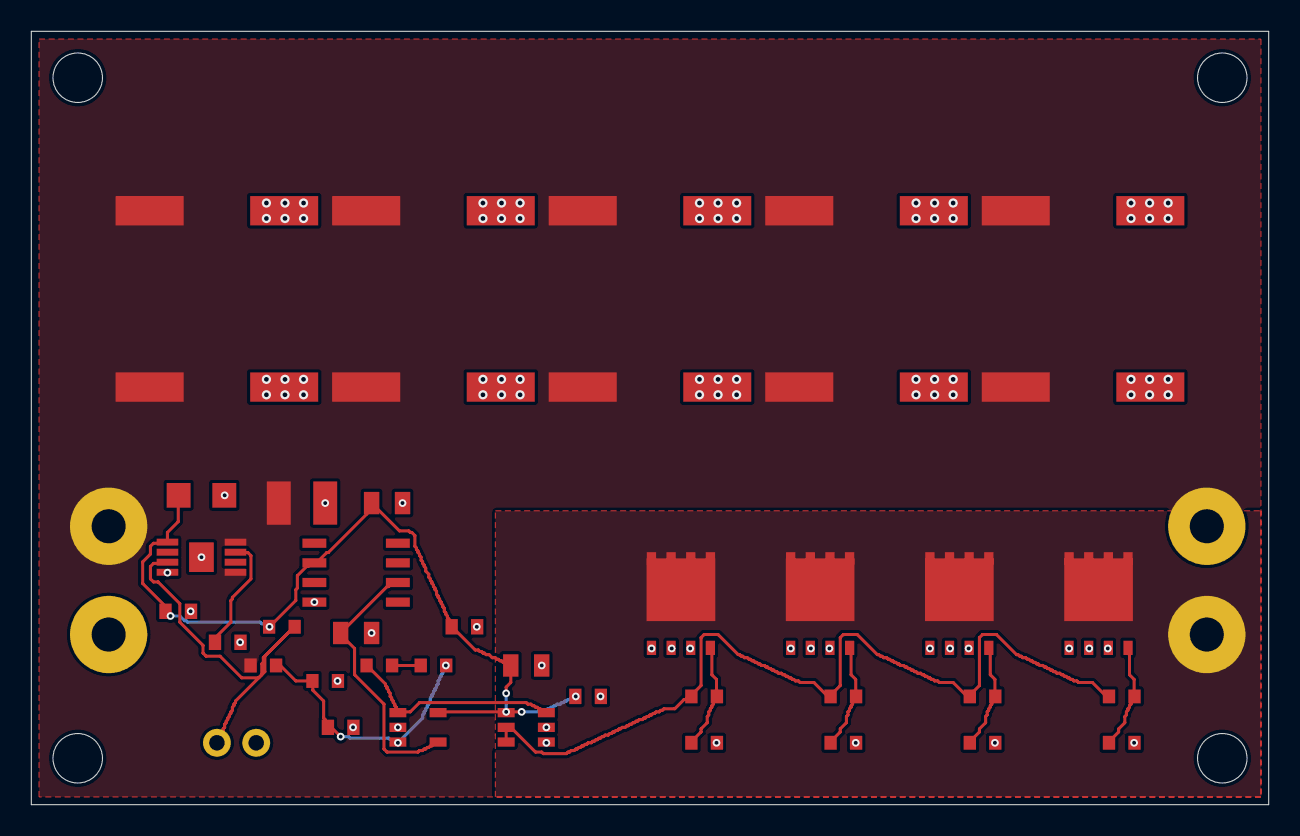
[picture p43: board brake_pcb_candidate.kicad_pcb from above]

Board: 2 copper layers, 80.0 x 50.0 mm, 48 parts (0 on the bottom side), 15 nets.

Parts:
C1, C2, C3, C4, C5, C6, C7, C8, C9, C10: 35SVPF120M; panasonic_f12
C11: 10 uF; c1210
C12: 10 uF; c1206
C13, C18, C19: 0.1 uF; c0603
C14, C16, C17: 1 uF; c0805
C15: 0.0001 uF; c0603
C20: 0.01 uF; c0603
H1, H2, H3, H4: mount_hole_32
J1: protected motor bus solder pads; paired_wire_terminal_7mm
J2: brake resistor solder pads; paired_wire_terminal_7mm
J3: bias ready monitor; pg_monitor_2p_254
Q1, Q2, Q3, Q4: BSC027N06LS5; bsc027n06ls5_pg_tdson8
R1: 100000 ohm; r0603
R2: 10700 ohm; r0603
R3, R31: 825000 ohm; r0603
R4: 10000 ohm; r0603
RG1, RG2, RG3, RG4: 2.2 ohm; r0603
RP1, RP2, RP3, RP4: 100000 ohm; r0603
U1: TPS7A1650DGNR; tps7a1650_dgn0008c
U2: REF5025IDR; ref5025_d0008a
U3: TLV3201DBVR; ti_dbv0005a
U4: UCC27511DBVR; ti_dbv0006a

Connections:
BIAS_5V: C12.1, C13.1, C16.1, C17.1, C18.1, C19.1, R4.1, U1.1, U2.2, U3.5, U4.1
BIAS_PG: J3.1, R4.2, U1.3
BIAS_PG_DELAY: C20.1, U1.7
BRAKE_REQUEST: R3.1, U3.1, U4.6
BUS: C1.1, C2.1, C3.1, C4.1, C5.1, C6.1, C7.1, C8.1, C9.1, C10.1, C11.1, J1.1, J2.1, R1.1, U1.5, U1.8
FEEDBACK_MID: R3.2, R31.1
GATE1: Q1.4, RG1.2, RP1.1
GATE2: Q2.4, RG2.2, RP2.1
GATE3: Q3.4, RG3.2, RP3.1
GATE4: Q4.4, RG4.2, RP4.1
GATE_DRIVE: RG1.1, RG2.1, RG3.1, RG4.1, U4.2, U4.3
GND: C1.2, C2.2, C3.2, C4.2, C5.2, C6.2, C7.2, C8.2, C9.2, C10.2, C11.2, C12.2, C13.2, C14.2, C15.2, C16.2, C17.2, C18.2, C19.2, C20.2, J1.2, J3.2, Q1.1, Q1.2, Q1.3, Q2.1, Q2.2, Q2.3, Q3.1, Q3.2, Q3.3, Q4.1, Q4.2, Q4.3, R2.2, RP1.2, RP2.2, RP3.2, RP4.2, U1.4, U1.9, U2.4, U3.2, U4.4, U4.5
REF_2V5: C14.1, U2.6, U3.4
SENSE: C15.1, R1.2, R2.1, R31.2, U3.3
SW_RETURN: J2.2, Q1.5, Q1.6, Q1.7, Q1.8, Q2.5, Q2.6, Q2.7, Q2.8, Q3.5, Q3.6, Q3.7, Q3.8, Q4.5, Q4.6, Q4.7, Q4.8

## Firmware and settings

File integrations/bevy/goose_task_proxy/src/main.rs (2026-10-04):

use crate::plant::GoosePlant;
use crate::world::{PhysicsClockProfile, SimulationWorld};
use rapier3d::{
    math::{Rotation, Vector},
    prelude::*,
};
use serde_json::{Value, json};
use std::{collections::HashMap, env, fs, time::Instant};
#[derive(Debug, thiserror::Error)]
pub enum RobotError {
    #[error("invalid robot contract: {0}")]
    Contract(String),
    #[error("nonfinite: {0}")]
    NonFinite(&'static str),
}
mod basis;
mod builder;
mod control;
mod plant;
mod world;

fn vector(v: &Value) -> Vector {
    Vector::new(
        v[0].as_f64().unwrap() as f32,
        v[1].as_f64().unwrap() as f32,
        v[2].as_f64().unwrap() as f32,
    )
}
fn nominal_gravity(c: &Value, q: [f64; 18], quat: [f64; 4]) -> [f64; 5] {
    let joints = c["joints"].as_array().unwrap();
    let passive = c["passive_linkage_joints"].as_array().unwrap();
    let bodies: HashMap<_, _> = c["bodies"]
        .as_array()
        .unwrap()
        .iter()
        .map(|b| (b["name"].as_str().unwrap(), b))
        .collect();
    let mut pivots = HashMap::new();
    pivots.insert("torso", vector(&c["root_origin_at_zero_m"]));
    for j in joints.iter().take(6).chain(passive) {
        pivots.insert(
            j["name"].as_str().unwrap(),
            vector(&j["pivot_world_at_zero_m"]),
        );
    }
    let mut positions = HashMap::new();
    positions.insert("torso", Vector::ZERO);
    let mut rotations = HashMap::new();
    rotations.insert(
        "torso",
        Rotation::from_xyzw(
            quat[1] as f32,
            quat[2] as f32,
            quat[3] as f32,
            quat[0] as f32,
        )
        .normalize(),
    );
    let mut axes = Vec::new();
    let mut centers = Vec::new();
    let mut forces = Vec::new();
    for (i, j) in joints.iter().take(6).enumerate() {
        let n = j["name"].as_str().unwrap();
        let p = j["parent"].as_str().unwrap();
        let pr = rotations[p];
        let pos = positions[p] + pr * (pivots[n] - pivots[p]);
        positions.insert(n, pos);
        let axis = vector(&j["axis_parent"]);
        axes.push(pr * axis);
        let rotation = pr * Rotation::from_axis_angle(axis, q[i] as f32);
        rotations.insert(n, rotation);
        let b = bodies[n];
        centers.push(pos + rotation * vector(&b["com_local_m"]));
        forces.push(Vector::new(
            0.0,
            0.0,
            -9.81 * b["mass_kg"].as_f64().unwrap() as f32,
        ));
    }
    for j in passive {
        let n = j["name"].as_str().unwrap();
        let p = j["parent"].as_str().unwrap();
        let pr = rotations[p];
        let pos = positions[p] + pr * (pivots[n] - pivots[p]);
        positions.insert(n, pos);
        let index = joints
            .iter()
            .position(|v| v["name"] == j["mimic_joint"])
            .unwrap();
        let angle = j["mimic_multiplier"].as_f64().unwrap() * q[index]
            + j["mimic_offset_rad"].as_f64().unwrap();
        let rotation = pr * Rotation::from_axis_angle(vector(&j["axis_parent"]), angle as f32);
        rotations.insert(n, rotation);
        let b = bodies[n];
        centers.push(pos + rotation * vector(&b["com_local_m"]));
        forces.push(Vector::new(
            0.0,
            0.0,
            -9.81 * b["mass_kg"].as_f64().unwrap() as f32,
        ));
    }
    std::array::from_fn(|i| {
        let p = positions[joints[i]["name"].as_str().unwrap()];
        -(i..centers.len())
            .map(|k| (centers[k] - p).cross(forces[k]).dot(axes[i]) as f64)
            .sum::<f64>()
    })
}

fn main() -> Result<(), Box<dyn std::error::Error>> {
    let args: Vec<_> = env::args().collect();
    let plant: GoosePlant = serde_json::from_slice(&fs::read(&args[1])?)?;
    let c: Value = serde_json::from_slice(&fs::read(&args[2])?)?;
    let control: control::GooseControlContract = serde_json::from_value(c.clone())?;
    use sha2::{Digest, Sha256};
    if format!("{:x}", Sha256::digest(fs::read(&args[2])?)) != plant.derived_contract_sha256
        || plant.model_sha256 != control.model_sha256
    {
        return Err("Plant/control identity mismatch".into());
    }
    plant.validate_collision_binding(&c)?;
    let cfg = &c["contact_mapping"];
    if cfg["method"] != "whole_sole_native_manifold_backward_euler_v1"
        || (cfg["per_foot_stiffness_n_m"].as_f64().unwrap() - 140142.1824).abs() > 1e-8
        || cfg["per_foot_damping_n_s_m"] != 12.0
        || cfg["prediction_band_m"] != 0.01
    {
        return Err("Unknown material mapping requires a new receiver revision".into());
    }
    if args.get(4).map(String::as_str) == Some("collision_filters") {
        let report = builder::probe_collision_filters(&plant)?;
        fs::write(&args[3], serde_json::to_vec_pretty(&report)?)?;
        println!(
            "Native collider-pair filtering probe completed; report {}",
            args[3]
        );
        return Ok(());
    }
    let mut simulation = SimulationWorld::new_with_profile(PhysicsClockProfile::Goose50);
    simulation
        .world
        .integration_parameters
        .num_internal_pgs_iterations = 32;
    simulation
        .world
        .integration_parameters
        .normalized_prediction_distance = 0.01;
    simulation
        .world
        .integration_parameters
        .warmstart_coefficient = 0.0;
    let floor = simulation.world.bodies.insert(RigidBodyBuilder::fixed());
    let ground = simulation.world.colliders.insert_with_parent(
        ColliderBuilder::halfspace(rapier3d::na::Unit::new_unchecked(Vector::Y))
            .friction(0.65)
            .collision_groups(InteractionGroups::new(
                Group::GROUP_1,
                Group::GROUP_1,
                InteractionTestMode::Or,
            )),
        floor,
        &mut simulation.world.bodies,
    );
    let robot = builder::GooseAssembly::build(&mut simulation, &plant, ground)?;
    let mut actuator = control::GooseActuatorState::new(&control)?;
    let mut trace = Vec::new();
    let scenario = args.get(4).map(String::as_str).unwrap_or("neutral");
    let ticks: usize = args.get(5).map(|s| s.parse().unwrap()).unwrap_or(500);
    for tick in 0..ticks {
        let state = robot.state(&simulation)?;
        let ff = nominal_gravity(&c, state.joint_position_rad, state.root_rotation_world_wxyz);
        let mut action = [0.0; 18];
        if scenario == "joint_motion" {
            let v = (tick as f64 * 0.02 * std::f64::consts::TAU * 0.25).sin();
            action[0] = 0.1 * v;
            action[5] = 0.1 * (1.0 - v) / 2.0;
            action[6] = 0.04 * v;
            action[12] = -0.04 * v;
        }
        if scenario == "jaw_full_range" {
            action[5] = ((tick as f64 * 0.02 * std::f64::consts::TAU * 0.125).sin() + 1.0) / 2.0;
        }
        let effort = actuator.update(
            &control,
            action,
            state.joint_position_rad,
            state.joint_velocity_rad_s,
            ff,
            1.0,
            false,
        )?;
        let start = Instant::now();
        robot.step(&mut simulation, effort.torque_nm)?;
        let ms = start.elapsed().as_secs_f64() * 1000.0;
        let state = match robot.state(&simulation) {
            Ok(v) => v,
            Err(e) => {
                let b = &simulation.world.bodies[robot.body_handles["torso"]];
                fs::write(
                    &args[3],
                    serde_json::to_vec_pretty(
                        &json!({"status":"failed","tick":tick+1,"error":e.to_string(),"raw_rotation_xyzw":b.rotation().to_array(),"root":b.translation().to_array(),"trace":trace}),
                    )?,
                )?;
                return Err(e.into());
            }
        };
        let up = -state.projected_gravity[2];
        let mut depth = 0.0_f64;
        let mut contacts = 0;
        for pair in simulation.world.narrow_phase.contact_pairs() {
            if pair.collider1 != ground && pair.collider2 != ground {
                continue;
            }
            for m in &pair.manifolds {
                for p in &m.points {
                    depth = depth.max(-p.dist as f64);
                    contacts += 1;
                }
            }
        }
        let mut post_depth = 0.0_f64;
        for shape in plant
            .colliders
            .iter()
            .filter(|g| g.name.ends_with("flexible_sole"))
        {
            let pose = simulation.world.bodies[robot.body_handles[&shape.body]].position()
                * builder::native_source_pose(shape.local_position_m, shape.local_rotation_wxyz)?;
            for v in shape
                .vertices_local_m
                .as_ref()
                .ok_or("Shoe hull points required")?
            {
                let corner =
                    Vector::from_array(basis::source_to_engine_vector(v.map(|x| x as f32)));
                post_depth = post_depth.max(-(pose * corner).y as f64);
            }
        }
        let observation = control.observation(
            &state,
            [0.0; 3],
            action,
            (tick + 1) as f64 * 0.02 * std::f64::consts::TAU * control.phase_frequency_hz,
        )?;
        let goal = control::TaskGoal {
            object_id: "probe_item".into(),
            position_world_m: [0.2, 0.1, 0.02],
            rotation_world_wxyz: [1.0, 0.0, 0.0, 0.0],
            placement_world_m: [0.4, -0.1, 0.02],
            valid: true,
        };
        let pickup = control.pickup_observation(
            observation,
            &state,
            &goal,
            control::PickupStage::Approach,
        )?;
        trace.push(json!({"observation":observation.to_vec(),"pickup_observation":pickup.to_vec(),"post_integration_sole_depth_m":post_depth,"pre_integration_contact_depth_m":depth,"observation_len":observation.len(),"action":action,"gravity_feedforward_nm":ff,"root_rotation_wxyz":state.root_rotation_world_wxyz,"tick":tick+1,"time_s":(tick+1) as f64*0.02,"upright":up,"root_position_m":state.root_position_world_m,
            "q":state.joint_position_rad,"qd":state.joint_velocity_rad_s,"torque_nm":effort.torque_nm,"normal_depth_m":depth,
            "contacts":contacts,"step_ms":ms,"jaw_pin_error_m":robot.jaw_pin_error_m(&simulation),"controller_updates":actuator.control_count,"integrations":tick+1}));
    }
    let mut native_support_count = 0;
    let mut native_shape_leaves = 0;
    let mut native_shapes = Vec::new();
    for (_, collider) in simulation.world.colliders.iter() {
        if collider.parent() == Some(floor) {
            continue;
        }
        let compound = collider
            .shape()
            .as_compound()
            .ok_or("Expected explicit one-child role compound")?;
        native_shape_leaves += compound.shapes().len();
        let group = &robot.collider_source_groups[native_shapes.len()];
        if group.len() != 1 {
            return Err("Role compound must contain one leaf".into());
        }
        let points = compound.shapes()[0]
            .1
            .as_convex_polyhedron()
            .ok_or("Expected convex role")?
            .points()
            .iter()
            .map(|p| basis::engine_to_source_vector(p.to_array()).map(f64::from))
            .collect::<Vec<_>>();
        native_shapes.push(json!({"name":group[0],"points_source_local_m":points}));
        for (_, shape) in compound.shapes() {
            native_support_count += if let Some(convex) = shape.as_convex_polyhedron() {
                convex.points().len()
            } else if shape.as_cuboid().is_some() {
                8
            } else {
                return Err("Unexpected native collision kind".into());
            };
        }
    }
    let report = json!({"native_shape_readback":native_shapes,"actual_native_shape_leaves":native_shape_leaves,"actual_native_support_points":native_support_count,"scenario":scenario,"schema":"goose_task_proxy_native_dynamic_probe_v1","candidate":plant.candidate_id,
        "source_geometry_count":robot.source_geometry_count,"native_collider_count":robot.collider_count,
        "collider_source_groups":robot.collider_source_groups,"jaw_constraints":1,"passive_springs":robot.passive_spring_count,"robot_bodies":robot.body_handles.len(),"body_measurements":robot.body_measurements,
        "native_dt_s":simulation.world.integration_parameters.dt,"native_solver_iterations":simulation.world.integration_parameters.num_solver_iterations,
        "physical_integrations":trace.len(),"trace":trace,"qualification":"measurements_require_M0_evaluator"});
    fs::write(&args[3], serde_json::to_vec_pretty(&report)?)?;
    println!(
        "Native articulated experiment completed; report {}",
        args[3]
    );
    Ok(())
}

#[cfg(test)]
mod collision_filter_tests;
#[cfg(test)]
mod foundation_tests;

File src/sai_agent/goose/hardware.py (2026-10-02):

"""Two-voltage DYNAMIXEL TTL driver with explicit commissioning and fail-stop.

Verified control-table facts: ROBOTIS eManual XM430-W350, XM540-W270,
XC330-M288. Nm/A coefficients are stall-based initial estimates, not calibrated
output torque. No ports are opened, EEPROM written or motors armed at import.
"""
from __future__ import annotations

import math
import time

import numpy as np

from .spec import load_spec

MODEL_NUMBERS={'xm430':1020,'xm540':1120,'xc330':1240}
CURRENT_UNIT_A={'xm430':.00269,'xm540':.00269,'xc330':.001}
INITIAL_NM_PER_A={'xm430':4.1/2.3,'xm540':10.6/4.4,'xc330':.93/1.8}


def signed(value:int,bits:int) -> int:
    return value-(1<<bits) if value&(1<<(bits-1)) else value


class DynamixelRobot:
    def __init__(self,ports:dict[str,str],calibration:dict|None=None,spec:dict|None=None):
        import dynamixel_sdk as sdk
        self.sdk=sdk;self.spec=spec or load_spec();self.joints=self.spec['joints']
        self.calibration=calibration;self.packet=sdk.PacketHandler(2.0)
        self.ports={};self.readers={};self.writers={};self.armed=False;self.last_command_s=None
        if set(ports)!=set(self.spec['motor_bus']) or len(set(ports.values()))!=len(ports):
            raise ValueError('12V and 5V require distinct named USB interfaces')
        try:
            for bus,path in ports.items():
                port=sdk.PortHandler(path)
                if not port.openPort() or not port.setBaudRate(self.spec['motor_bus'][bus]['baud']):
                    port.closePort();raise OSError('Cannot open bus '+bus)
                self.ports[bus]=port
                reader=sdk.GroupSyncRead(port,self.packet,126,21)
                writer=sdk.GroupSyncWrite(port,self.packet,102,2)
                for j in self.joints:
                    if j['bus']==bus and not reader.addParam(j['motor_id']):raise OSError('Cannot register motor')
                self.readers[bus]=reader;self.writers[bus]=writer
        except Exception:
            self.close();raise

    def _read(self,j,address,size):
        value,comm,error=getattr(self.packet,f'read{size}ByteTxRx')(self.ports[j['bus']],j['motor_id'],address)
        if comm!=self.sdk.COMM_SUCCESS or error:raise OSError(f"{j['name']} read {address}: comm={comm},error={error}")
        return value

    def _write(self,j,address,size,value):
        comm,error=getattr(self.packet,f'write{size}ByteTxRx')(self.ports[j['bus']],j['motor_id'],address,int(value)&((1<<(8*size))-1))
        if comm!=self.sdk.COMM_SUCCESS or error:raise OSError(f"{j['name']} write {address}: comm={comm},error={error}")

    def inspect(self):
        out=[]
        for j in self.joints:
            values={name:self._read(j,address,size) for name,address,size in
                    [('model_number',0,2),('firmware',6,1),('operating_mode',11,1),
                     ('current_limit_ticks',38,2),('torque_enabled',64,1),('hardware_error',70,1),
                     ('watchdog_ticks',98,1),('voltage_tenths',144,2),('temperature_C',146,1)]}
            values.update(joint=j['name'],bus=j['bus'],motor_id=j['motor_id'])
            if values['model_number']!=MODEL_NUMBERS[j['servo']]:raise ValueError('Wrong motor model on '+j['name'])
            out.append(values)
        return out

    def commission_limits(self):
        """Explicit bench operation. Leaves torque OFF; never called by arm."""
        self.disarm();self.inspect()
        for j in self.joints:
            unit=CURRENT_UNIT_A[j['servo']];servo=self.spec['servos'][j['servo']]
            limit=math.floor(servo['current_limit_initial_A']/unit)
            self._write(j,11,1,0)  # EEPROM current control, shared by simulation PD.
            self._write(j,38,2,limit)
            self._write(j,9,1,10)  # 20 us return delay, EEPROM, bench-only.
            self._write(j,98,1,0);self._write(j,102,2,0)
            if self._read(j,11,1)!=0 or self._read(j,38,2)!=limit:raise OSError('Commissioning readback failed')
        return self.inspect()

    def validate_ready(self):
        """Read-only preflight, also used before energizing hybrid CAN peers."""
        if not self.calibration or self.calibration.get('commissioning_passed') is not True:
            raise ValueError('Physical joint sign/zero, current/torque and IMU commissioning required')
        names=[j['name'] for j in self.joints]
        if self.calibration.get('joint_names')!=names:raise ValueError('Calibration joint order mismatch')
        for key in ('zero_ticks','sign','Nm_per_A'):
            values=np.asarray(self.calibration[key],float)
            if values.shape!=(len(names),) or not np.isfinite(values).all():raise ValueError('Incomplete calibration '+key)
        if any(v not in (-1,1) for v in self.calibration['sign']) or min(self.calibration['Nm_per_A'])<=0:
            raise ValueError('Invalid motor calibration')
        statuses=self.inspect()
        if len(statuses)!=len(self.joints):raise ValueError('Incomplete motor inspection')
        for j,status in zip(self.joints,statuses):
            cap=math.floor(self.spec['servos'][j['servo']]['current_limit_initial_A']/CURRENT_UNIT_A[j['servo']])
            if status['operating_mode']!=0 or not 0<status['current_limit_ticks']<=cap:
                raise ValueError('Hardware current limit/mode not commissioned: '+j['name'])
            if status['hardware_error'] or status['torque_enabled']:raise ValueError('Motor not in healthy torque-off state')
            voltage=status['voltage_tenths']/10
            if not ((10.6<=voltage<=14.0) if j['bus']=='12v' else (4.75<=voltage<=5.25)):
                raise ValueError('Voltage outside commissioning envelope')
            if status['temperature_C']>=60:raise ValueError('Motor above initial commissioning temperature gate')
        return [dict(status,output_Nm_per_A=float(self.calibration['Nm_per_A'][i]))
                for i,status in enumerate(statuses)]

    def arm(self):
        try:
            self.validate_ready()
            # Validate every bus and motor before enabling any actuator.
            for j in self.joints:
                self._write(j,98,1,0);self._write(j,102,2,0);self._write(j,98,1,5)
            for j in self.joints:
                self._write(j,64,1,1)
            self.armed=True;self.last_command_s=time.monotonic()
        except Exception:
            self.disarm();raise
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

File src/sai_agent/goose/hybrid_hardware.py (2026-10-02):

"""Current 18-axis binding and torque dispatch: 17 AK CAN + one XC330 TTL.

An injectable TTL endpoint implements the same five operations as a one-axis
DynamixelRobot. Unknown A2 profiles prevent arming; raw passive capture remains
available in can_transport. Software stopping is best effort, not an E-stop.
"""
from __future__ import annotations

from dataclasses import dataclass
import math
import threading
import time
from typing import Protocol

import numpy as np

from .can_transport import WaveshareCan
from .cubemars_v3 import (AkStatus, CommissionedAkProfile, DisableAcknowledgement,
                         current_command, decode_status, disable)


@dataclass(frozen=True)
class AxisBinding:
    name: str
    actuator: str
    bus: str
    node_id: int | None
    range_rad: tuple[float, float]
    continuous_limit_nm: float
    speed_limit_rad_s: float


def bind_axes(contract: dict, layout: dict) -> tuple[AxisBinding, ...]:
    if contract.get("active_axes") != 18 or contract.get("robot") != "Goose_V0.1":
        raise ValueError("Expected current Goose 18-axis contract")
    names = contract["joint_order"]
    if len(names) != 18 or len(set(names)) != 18:
        raise ValueError("Duplicate/missing active axes")
    indexed = {j["name"]: j for j in contract["joints"]}
    if len(indexed) != 18 or set(indexed) != set(names):
        raise ValueError("Joint definitions do not match order")
    mapping = {}
    buses = layout["motor_buses"]
    if {b["name"] for b in buses} != {"can_a", "can_b"} or len(buses) != 2:
        raise ValueError("Two explicitly named CAN buses required")
    for bus in buses:
        ids = bus["proposed_node_ids"]
        if len(ids) != len(bus["axes"]) or len(set(ids)) != len(ids):
            raise ValueError("CAN IDs missing or duplicated within bus")
        for name, node in zip(bus["axes"], ids):
            if name in mapping or type(node) is not int or not 1 <= node <= 255:
                raise ValueError("Duplicate axis/invalid CAN ID")
            mapping[name] = (bus["name"], node)
    if layout["ttl_branch"]["axis"] != "head_roll" or "head_roll" in mapping:
        raise ValueError("head_roll requires its own TTL branch")
    mapping["head_roll"] = ("ttl_5v", None)
    if set(mapping) != set(names):
        raise ValueError("Every active axis must have exactly one hardware endpoint")
    bindings = []
    for name in names:
        joint = indexed[name]
        actuator = joint["actuator"]
        if actuator not in ("ak40_10_v3", "ak45_10_v3", "ak45_36_v3",
                            "ak45_36_v3_parallel_crank_1_to_1", "xc330_m288_t"):
            raise ValueError("Unexpected selected actuator")
        bus, node = mapping[name]
        if (bus == "ttl_5v") != (actuator == "xc330_m288_t"):
            raise ValueError("Actuator and electrical bus do not match")
        low, high = joint["range_rad"]
        limit = joint["continuous_design_limit_nm"]
        speed = joint["speed_limit_rad_s"]
        if not all(math.isfinite(v) for v in (low, high, limit, speed)) or low >= high or min(limit, speed) <= 0:
            raise ValueError("Invalid physical joint limits")
        bindings.append(AxisBinding(name, actuator, bus, node, (low, high), limit, speed))
    return tuple(bindings)


class TtlAxis(Protocol):
    def validate_ready(self) -> list[dict]: ...
    def arm(self) -> None: ...
    def disarm(self) -> None: ...
    def read_encoders(self) -> dict: ...
    def write_torques(self, torque_nm) -> None: ...
    def close(self) -> None: ...


def xc330_axis_spec(binding: AxisBinding, *, motor_id: int, current_limit_a: float) -> dict:
    """Adapt the existing verified DYNAMIXEL driver to the current single axis.

    Hardware current limits and Nm/A still require physical commissioning.
    No historical beak_drive or 12V joint is copied into this specification.
    """
    if binding.name != "head_roll" or binding.actuator != "xc330_m288_t":
        raise ValueError("Only the current head_roll XC330 belongs on this branch")
    if type(motor_id) is not int or not 1 <= motor_id <= 252:
        raise ValueError("Invalid TTL device ID")
    if not math.isfinite(current_limit_a) or not 0 < current_limit_a <= .36:
        raise ValueError("TTL commissioning current must stay within initial 0.36A cap")
    return {"joints": [{"name": binding.name, "servo": "xc330", "bus": "5v",
                        "motor_id": motor_id, "range_rad": list(binding.range_rad),
                        "motor_sign": 1, "motor_zero_ticks": 2048}],
            "servos": {"xc330": {"current_limit_initial_A": current_limit_a}},
            "motor_bus": {"5v": {"baud": 1_000_000}}}


def open_current_head_roll(binding: AxisBinding, path: str, *, motor_id: int,
                           current_limit_a: float, calibration: dict):
    from .hardware import DynamixelRobot
    if calibration.get("joint_names") != ["head_roll"] or calibration.get("commissioning_passed") is not True:
        raise ValueError("Current single-axis TTL commissioning required")
    gains = calibration.get("Nm_per_A", [])
    if len(gains) != 1 or not math.isfinite(gains[0]) or gains[0] <= 0:
        raise ValueError("Physical XC330 torque/current calibration required")
    if binding.continuous_limit_nm > math.floor(current_limit_a / .001) * .001 * gains[0]:
        raise ValueError("TTL continuous torque exceeds commissioned current")
    return DynamixelRobot({"5v": path}, calibration=calibration,
                          spec=xc330_axis_spec(binding, motor_id=motor_id,
                                              current_limit_a=current_limit_a))
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

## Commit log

2026-09-12 Add licensed robot models, GPU training and validated flat locomotion
    [arm_gripper_0.obj, arm_gripper_1.obj, arm_gripper_2.obj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]
2026-09-12 Add playable Godot profile and verified 20/40 mm stair transfer
2026-09-12 Record native Unity acceptance and isolated 60 mm stair experiments
2026-09-12 Package tested experimental 60 mm stair profiles and transfer evidence
2026-09-12 Add Sai_Agent_002 flat cargo variant and robot family catalog (#1)
    [arm_gripper_0.obj, arm_gripper_1.obj, arm_gripper_2.obj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]
2026-09-27 refactor: organize robot assets and engineering rules
    [arm_gripper_0.obj, arm_gripper_1.obj, arm_gripper_2.obj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]
2026-09-27 fix: isolate evaluation artifacts and verify installed wheels
2026-09-29 feat(goose): preserve design milestone and accepted fuller exterior baseline
    [ankle_-1.obj, ankle_1.obj, ankle_boot_-1.obj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]
2026-09-29 feat(goose): checkpoint foot structure and prioritize system training handoff
    [foot_support_exploded_quad.blend, left_foot_load_plate.obj, left_foot_load_plate.step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]
2026-09-29 Add Goose stage-one physical parameter handoff
    [fixed_upper_bill_contact.obj, goose_stage_one_quad.blend, head_collision.obj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]
2026-09-29 Deliver Goose stage-two linkage and physical parameter candidate
    [fixed_upper_bill_contact.obj, goose_stage_two_quad.blend, head_collision.obj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]
2026-09-30 Add native Goose manufacturing skins and interface prototypes
    [ak40_10_v3_output_adapter.step, ak40_10_v3_output_adapter.stl, ak40_10_v3_stationary_front_ring.step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]
2026-09-30 Add dimensioned pitch forks and compliant sole candidates with failed frame screen
    [left_flexible_sole.step, left_flexible_sole.stl, left_shin_bearing_outer_retainer.step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]
2026-09-30 Strengthen native Goose forks and record bounded foot and turning checks
    [left_shin_bearing_outer_retainer.step, left_shin_bridge.step, left_shin_distal_front_ring.step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]
2026-09-30 Normalize fastener CSV and refresh validated source bindings
    [native_pitch_fastener_bom.csv]
2026-10-01 Deliver same-source Goose hardware and head-shell checkpoint through LFS
    Current file tree from local source commit 81bc220b45553e1c20e488c0d40312580915380f.
    Four original large assets keep SHA256/length; only their Git storage becomes LFS.
    Unpublished original commit history remains on the local engineering branch unchanged.
    Snapshot does not grant manufacturing, appearance, training or full-stage release.
    [beak_coupler_000.obj, beak_coupler_collision_000.obj, beak_input_bush_candidate.step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]
2026-10-02 Publish Goose 460-part training checkpoint and project overview
    [beak_input_bush_candidate_collision_000.obj, beak_input_bush_candidate_collision_001.obj, beak_input_bush_candidate_collision_002.obj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]
2026-10-02 Point Sai Lab readers at the current Goose checkpoint
2026-10-02 feat(gorilla): save AA3 C15 stage with segmented feet
    [appearance_c.blend, back_fastener_0p125_2p216.obj, back_fastener_0p125_2p487.obj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]
2026-10-04 Deliver verified eleven-leaf Goose M0 Sim2Sim entry
    [head_upper_bill_envelope.obj, left_flexible_sole.obj, left_shin_envelope.obj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]
2026-10-04 Verify selective adjacent collision filters across Goose source and receiver
    [main.rs]
2026-10-04 Reject contradictory Goose wing-door CAD query results
2026-10-04 Repair folded Goose torso skins in an isolated CAD candidate
    [torso_service_shell_left_aft.step, torso_service_shell_left_aft.stl, torso_service_shell_left_fore.step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]
2026-10-04 Implement manual Goose wing hinges and closure in a separate CAD candidate
    Replace the six folded torso skins, add nominal shoulder-pin retention and removable thumb closures, and integrate the 24-part delta into the 478-object assembly and full SI ledger. Preserve failed CAD inputs and frozen Sim2Sim 003; publish bounded fit/static checks and four source-matched renders without claiming whole-robot manufacture or dynamics acceptance.
    [manual_wing_service_body_parameters.csv, manual_wing_service_bom.csv, manual_wing_service_bom.xlsx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]
2026-10-04 Bind Goose AK48 electrical documentation and current actuator endpoints
    Record exact V1.11 driver voltage and connector data plus the selected KV protocol tables. Validate all 18 actuator endpoints and distinguish ideal brake equilibrium from unqualified transient protec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
    [current_actuator_endpoints.csv]
2026-10-04 Add absolute-voltage Goose brake circuit comparison and fault traces
    [absolute_brake_chopper.kicad_sch, candidate_bom.csv]
2026-10-04 Add native Goose brake installation candidate and motion clearance evidence
    [brake_bracket_0.step, brake_bracket_0.stl, brake_bracket_0_chassis_m3x12.step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]
2026-10-04 Verify instance-scoped Goose collision filters in native Godot Jolt
2026-10-04 Add native Goose brake PCB checkpoint and freeze virtual training inputs
    [brake_pcb_candidate.kicad_pcb, brake_pcb_candidate.kicad_sch, candidate_bom.csv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]
2026-10-04 Add versioned virtual grasp samples and bounded admission evidence
2026-10-18 Replace Goose V0.2 training collisions with14 convex shapes and native grip boundary
    Preserve hardware mass, complete inertia, axes and drives. Add direct native contact references and retain rejection evidence for291-leaf complexity and the missing lower grip edge. Document unmeasured contact calibration and relative performance limits.
2026-10-18 Document final04 measured timing and contact calibration limits
2026-10-18 Record Goose grip evidence and prioritize heavy ground dragging
2026-10-18 Add 420 mm low-handle cart prototype and static qualification limits
2026-10-18 Retain rejected hitch evidence and add collinear420mm cart static prototype
2026-10-18 Close local Teacher mouth probe005 without hardware acceptance
2026-10-19 Save source-aligned Goose V0.2 physical07 experimental checkpoint
    Preserve immutable06/07 runtime packages, authoritative07 whole native CAD, selected source replacements and checks. Physical07:16.5838988627kg,23bodies,18drives,28convex leaves. Same source MCI and visual identity; default04 remains unchanged. Finite2.13mm saved-point prototype exception and manufacturing/STEP/thin-rim failures remain explicit. No stable loaded walking or transport qualification.
2026-10-19 Publish source-bound Goose V0.2 physical08 experimental hardware
    Retain the immutable 16.728453580 kg native assembly, full body inertials and 28-convex runtime. Add real AK45-10 yaw drives and the H900 Oldham engineering candidate with a 1.8 Nm chain cap. Preserve source-bound limitations and failed loaded-walking status; keep04 as the default. No stable training or manufacturing qualification.
2026-10-20 Audit Goose four reported surface defects against immutable physical08 native source
    Remove no physical material in this audit. Bind the old, saved08 and same-native refined display comparisons to exact source hashes. Record repaired old display outliers and remaining native hip/foot openings and manufacturing limits; review meshes do not replace physical08.
2026-10-21 design(goose): refine monochrome enclosure and require pre-delivery design review
2026-10-21 design(goose): apply aesthetic review to drafts and reject failed enclosure prototype
2026-10-22 Add native Goose enclosure checkpoint and document ankle cover motion limits
2026-10-22 Add theme-coloured Goose enclosure study and update gallery
2026-10-23 Preserve selected Goose upper enclosure native patch
2026-10-23 Navigate to Goose 061 upper CAD and mark older appearance studies historical
2026-10-23 Archive Goose 061 complete native candidate with explicit enclosure rejection
2026-10-24 Archive Goose 038 native candidate with explicit unresolved geometry
    Preserve the full editable assembly, split reproducible source archive, seven actual views and same-source evidence. Keep the overall design and hardware rejection explicit; do not change Frozen15 or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
